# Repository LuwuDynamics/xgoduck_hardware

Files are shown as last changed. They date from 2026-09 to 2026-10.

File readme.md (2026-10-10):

<div align="center">



# XGO-Duck

**English** · [简体中文](README_CN.md)

**Build a robot duck. Explore how it moves. Make it your own.**

A 3D-printable biped robot built around Arduino UNO Q and 15 serial servos.

[Assembly guide](Assembly_Guide.pdf) · [Bill of materials](BOM.md) · [Runtime](https://github.com/LuwuDynamics/xgoduck_runtime_arduino) · [Training](https://github.com/LuwuDynamics/xgoduck_rl)

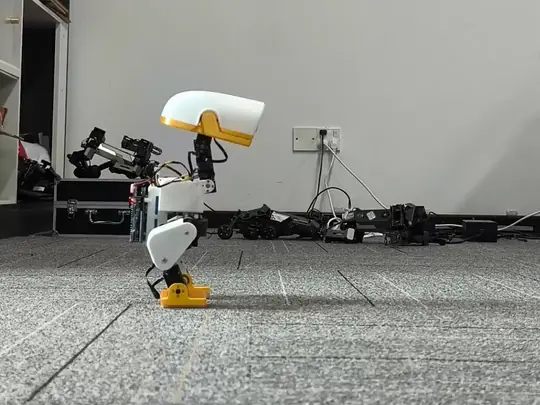
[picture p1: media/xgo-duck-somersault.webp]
A duck-shaped biped robot performing a somersault in a looping animation


*A clean somersault · CyberBionic Maker*

</div>

## Meet XGO-Duck

XGO-Duck is a duck-shaped biped robot adapted by **Luwu Dynamics** from Pollen Robotics' **Microduck**. It combines a printable structure, fifteen Feetech 1910 servos, an Arduino UNO Q, and a custom expansion board with an IMU and servo interfaces.

This repository is the hardware starting point: **print the parts, prepare the electronics, and assemble the robot**. Companion repositories provide the onboard runtime and reinforcement-learning tools, connecting a physical build with motion experiments.

| Build | Run | Experiment |
| --- | --- | --- |
| Print the body, legs, neck, head and soft parts. Assemble with the illustrated guide. | Configure and calibrate the robot through the companion runtime's browser interface. | Study the simulation, train policies and explore your own motions. |
| [Hardware files](#hardware-files) | [Onboard runtime](https://github.com/LuwuDynamics/xgoduck_runtime_arduino) | [RL tools](https://github.com/LuwuDynamics/xgoduck_rl) |

## A closer look

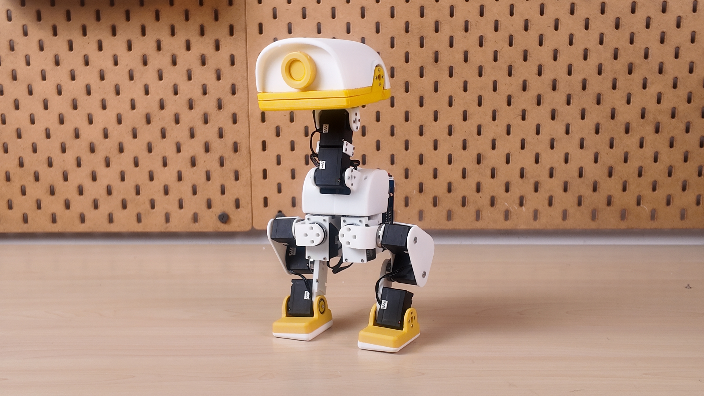
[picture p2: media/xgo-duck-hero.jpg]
XGO-Duck standing on a workbench, with a white printed body, yellow beak and feet, and exposed leg joints


*XGO-Duck prototype — printed parts, articulated legs, and a movable head and beak.*

<table>
  <tr>
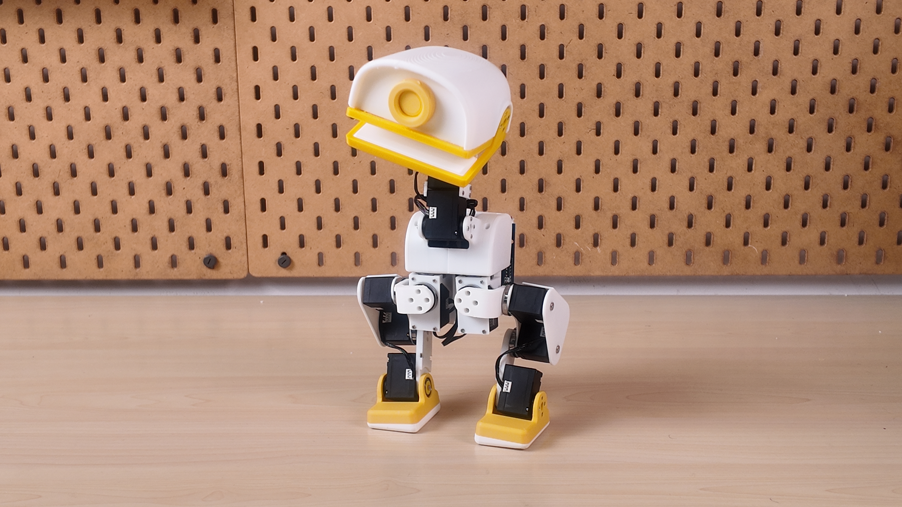
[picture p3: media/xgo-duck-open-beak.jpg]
Front view of XGO-Duck with its beak open
    <td align="center" width="62%"><br><strong>A movable head and beak</strong><br>Four neck/head joints and a separate mouth servo.</td>
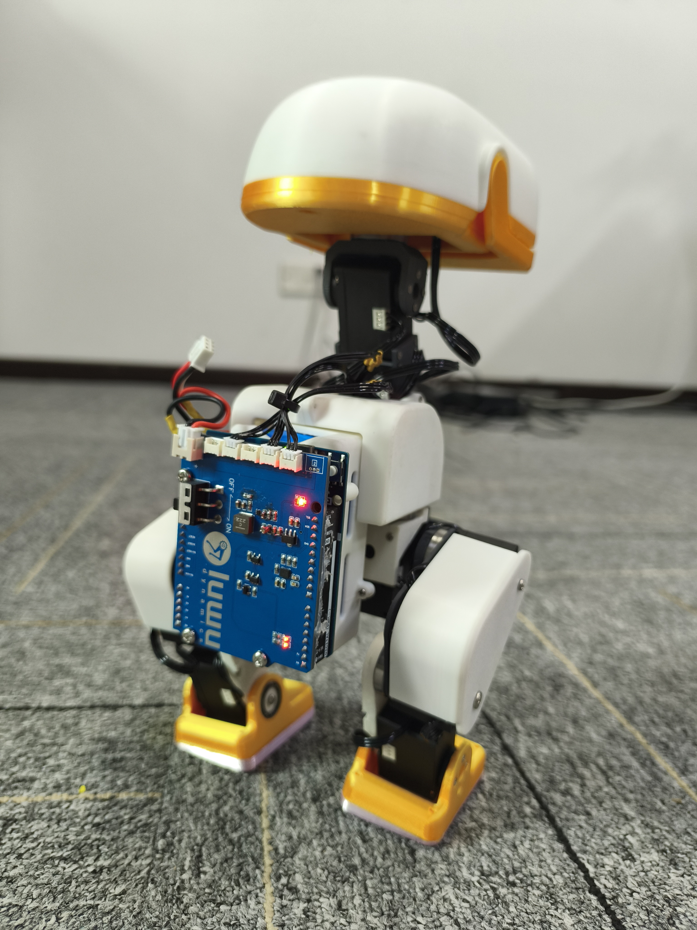
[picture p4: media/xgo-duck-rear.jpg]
Rear prototype view showing the blue expansion board and servo wiring
    <td align="center" width="38%"><br><strong>Electronics you can inspect</strong><br>Rear-mounted controller stack and accessible wiring.</td>
  </tr>
</table>

The photos show project prototypes. Follow the assembly guide and matching board files for your build revision.

## Hardware at a glance

| Subsystem | What it uses | Role |
| --- | --- | --- |
| Controller | Arduino UNO Q | Linux host for policy inference and web UI; STM32 MCU for servo and sensor communication |
| Actuation | 15 Feetech 1910 serial servos | 10 leg joints, 4 neck/head joints, and 1 mouth joint |
| Expansion board | Luwu UNO Q expansion board | Power distribution, servo connections and IMU integration |
| Motion sensing | QMI8658A 6-axis IMU | Acceleration and angular-velocity feedback |
| Structure | STL parts | Body, leg, neck and head components |
| Soft parts | TPU-designated STL files | Foot soles and mouth parts |

The motion policy outputs targets for **14 joints**; the mouth servo is controlled separately. Component details and purchasing checks are collected in the [BOM notes](docs/BOM.md).

### How the system connects

```mermaid
flowchart TD
    UI[Browser: setup, calibration and control] <--> HOST[UNO Q Linux: ONNX policy and web UI]
    RL[Training computer: simulation and RL] -->|Export ONNX policy| HOST
    HOST <-->|Arduino Bridge| MCU[UNO Q STM32: servo and IMU loop]
    MCU <-->|Serial bus| SERVOS[15 Feetech 1910 servos]
    IMU[QMI8658A IMU] -->|Sensor feedback| MCU
    BOARD[Custom expansion board] --- SERVOS
    BOARD --- IMU
```

This is a functional overview; use the board design and assembly documentation for electrical connections.

## Start your build

> **Hardware correction — 2026-10-02:** The old ArduinoUnoQ PCB reverses GND and SIGNAL on **U3, U4 and U5**. Owners of previously manufactured boards should disconnect power and follow the [old-board wiring instructions](PCBA/README.md#english-notice-for-previously-manufactured-boards). Pin 2 power is unchanged. Schematic and PCB sources are updated.

### 1. Prepare parts and electronics

Open the [bill of materials](BOM.md) for the robot purchasing list, supplier links and battery requirements, and [PCBA/](PCBA/) for the expansion-board files. The robot BOM and PCB manufacturing BOM serve different purposes: a finished expansion board already includes its board-level components.

| Part | Quantity |
| --- | ---: |
| Arduino UNO Q (2 GB / 4 GB) | 1 |
| [Robot expansion board — Luwu Dynamics Store](https://shop.xgorobot.com/products/robot-driver-board?variant=67594424713467) | 1 |
| Feetech 1910 servo | 15 |
| AMP 3-pin servo cable | 15 |
| Battery pack, listed as “18650 battery 8.4V” | 1 |
| 8.4 V Li-ion battery charger with 5.5 × 2.1 mm DC barrel plug (DC5521) | 1 |
| M2 × 6 countersunk, flat-end self-tapping screw | 200 |
| M2.3 × 8 flat-top round-head, flat-end self-tapping screw | 6 |
| M3 × 16 round-head machine screw | 4 |
| 10 × 15 × 3 mm bearing | 2 |
| 16 × 22 × 4 mm bearing | 11 |

Quantities reproduce the purchasing list, including screw quantities. Confirm the pack, charger, connector polarity and power requirements using the [component notes](docs/BOM.md) before sourcing or powering the build.

**Identify the three fasteners before ordering.** Items 7 and 8 are self-tapping screws with flat ends. Items 8 and 9 share the same rounded side profile; item 8 has a flat top, while item 9 has the gently domed top shown in the photo below and a machine thread. The following shape guide is illustrative. See the [product photo and size references](BOM.md#fastener-identification) in the BOM.

Shape guide for the M2 by 6 countersunk flat-end self-tapping screw, M2.3 by 8 flat-top round-head flat-end self-tapping screw, and M3 by 16 domed round-head machine screw

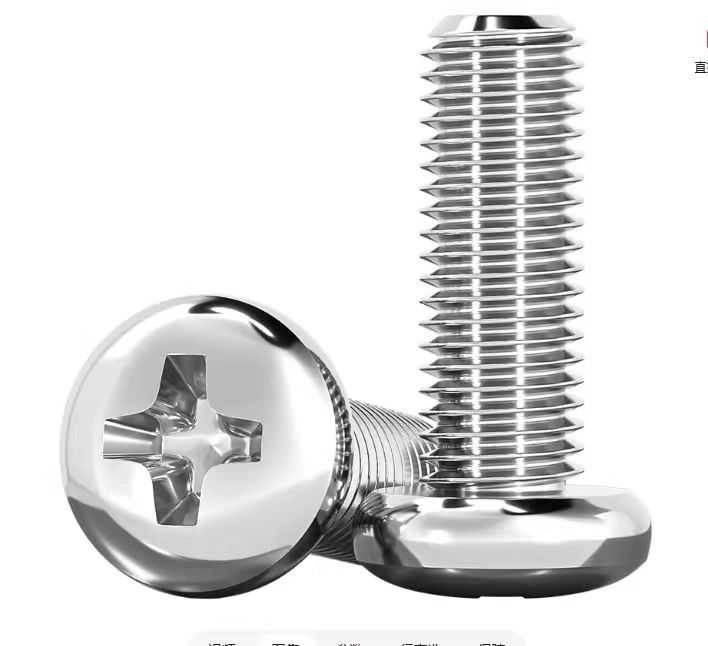
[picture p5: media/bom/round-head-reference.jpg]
Reference photo of the intended shallow, gently domed round screw head for item 9 only


*Item 9 has the domed top shown here. Item 8 has the same rounded sides but a flat top. The photo is a head-style reference, not a size or thread specification.*

### 2. Print the structure

Download the models from [structure/](structure/). The filenames carry useful assembly information:

| Filename pattern | Meaning | Example |
| --- | --- | --- |
| `2x_` | Print two copies | `2x_shank.stl` |
| `left_` / `right_` | Separate left and right parts | `left_foot.stl`, `right_foot.stl` |
| `tpu` | Flexible part | `2x_foot_bottom_tpu.stl`, `mouth_up_tpu.stl` |

Use the [print inventory](docs/PRINTING.md) to track parts. Test a servo mount and bearing fit before printing the full set; a complete validated print profile is still to be documented.

### 3. Configure servos and assemble

Prepare each servo's ID and center position using the [runtime setup instructions](https://github.com/LuwuDynamics/xgoduck_runtime_arduino#first-time-servo-setup), then follow [Assembly_Guide.pdf](Assembly_Guide.pdf).

| Assembly reference | Focus |
| --- | --- |
| Page 1 | Servo ID placement |
| Pages 2–5 | Shaft preparation, initial structure and cable routing |
| Pages 6–15 | Legs, feet and soles |
| Pages 16–23 | Head and neck mechanisms |
| Pages 24–25 | Final assembly |

The [build guide](docs/BUILD_GUIDE.md) adds preparation and inspection checkpoints. Configure one servo at a time, label its ID, and leave cable clearance through each joint's movement.

### 4. Calibrate and bring it to life

Install the [onboard runtime](https://github.com/LuwuDynamics/xgoduck_runtime_arduino), verify servo and IMU feedback, and complete calibration with the robot supported. Start with the default pose before motion trials.

The runtime includes **walk, get-up and pick policies**, plus separate mouth control. Their behavior depends on the assembled hardware, calibration and test conditions. Using the bundled policies does not require training a new model.

## Hardware files

| Path | Contents |
| --- | --- |
| [Assembly_Guide.pdf](Assembly_Guide.pdf) | 25-page illustrated assembly reference |
| [BOM.md](BOM.md) | Whole-robot purchasing list, supplier links and battery reference image |
| [structure/](structure/) | Printable STL models |
| [PCBA/ArduinoUnoQ.SchDoc](PCBA/ArduinoUnoQ.SchDoc) | Altium schematic source |
| [PCBA/ArduinoUnoQ.PcbDoc](PCBA/ArduinoUnoQ.PcbDoc) | Altium PCB source |
| [PCBA/ArduinoUnoQ.pdf](PCBA/ArduinoUnoQ.pdf) | Board layout and dimension drawing |
| [PCBA/ArduinoUnoQ.DWG](PCBA/ArduinoUnoQ.DWG) · [STEP model](PCBA/ArduinoUnoQ.step) | Board outline and mechanical integration model |
| [PCBA/BOM.xlsx](PCBA/BOM.xlsx) · [Pick-and-place data](PCBA/Pick%20Place%20for%20ArduinoUnoQ.csv) | Expansion-board assembly materials and placement coordinates |
| [docs/](docs/) | Build, printing, BOM and troubleshooting notes |

## From hardware to your own behavior

| Repository | Purpose |
| --- | --- |
| **[xgoduck_hardware](https://github.com/LuwuDynamics/xgoduck_hardware)** | Mechanical parts, electronics, BOM and assembly |
| **[xgoduck_runtime_arduino](https://github.com/LuwuDynamics/xgoduck_runtime_arduino)** | UNO Q firmware, policy execution, browser setup and control |
| **[xgoduck_rl](https://github.com/LuwuDynamics/xgoduck_rl)** | Simulation, reinforcement-learning training and policy export |

Keep the hardware, runtime and policy revisions together in your build record. This makes it easier to reproduce a working configuration and diagnose changes.

## Origins and contributions

XGO-Duck builds on [Microduck](https://github.com/pollen-robotics/microduck) and [microduck_rl](https://github.com/pollen-robotics/microduck_rl) by **Pollen Robotics**. The duck form, 15-servo arrangement and policy joint order originate in that work. Luwu Dynamics' adaptation focuses on **Arduino UNO Q, Feetech 1910 servos, the custom expansion board, and the matching software/model integration**. See [origins and adaptations](UPSTREAM.md).

Build reports, tested print settings, clearer assembly photos and reproducible fixes are welcome. Read [CONTRIBUTING.md](CONTRIBUTING.md) or [open an issue](https://github.com/LuwuDynamics/xgoduck_hardware/issues).

For reuse terms, consult [LICENSING.md](LICENSING.md) and the applicable file-level notices. Contact: **hello@xgorobot.com**.

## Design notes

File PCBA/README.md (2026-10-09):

# ArduinoUnoQ PCBA

## 合作 PCB 供应商 / PCB supplier contact

**深圳诚和欣科技有限公司**是陆吾智能的合作 PCB 供应商。开发者如需咨询本项目 PCB 制作相关事宜，可通过以下方式联系。

Developers can contact Luwu Dynamics' partner PCB supplier below about PCB manufacturing for this project.

| 项目 / Item | 信息 / Details |
| --- | --- |
| 公司 / Company | 深圳诚和欣科技有限公司 |
| 联系人 / Contact | 刘晓亚 / Liu Xiaoya |
| 电话 / Phone | +86 13537846596 |
| 邮箱 / Email | [liu@chxpcba.com](mailto:liu@chxpcba.com) |
| 地址 / Address | 深圳市宝安区西乡簕竹角鸿都工业园 3 栋 2 楼 1 区 / Area 1, 2nd Floor, Building 3, Hongdu Industrial Park, Lezhujiao, Xixiang, Bao'an District, Shenzhen, China |

咨询时建议注明 **XGO-Duck / ArduinoUnoQ 扩展板**，并提供所用工程版本、制作数量及需求，便于沟通与报价。

When enquiring, mention **XGO-Duck / ArduinoUnoQ expansion board** and include the design revision, quantity and requirements to help the supplier prepare a quotation.

## 中文：已生产 PCB 的处理说明（2026-10-02）

**U3、U4、U5 舵机接口的 GND 与 SIGNAL 在旧版设计中接反。使用旧文件生产的 PCB，请先断电核对并处理，再连接舵机。U2 是稳压器，不属于此次换线范围。**

本次更新替换 `ArduinoUnoQ.SchDoc` 和 `ArduinoUnoQ.PcbDoc`。下面的旧版映射已在更新前的提交 [`703bfd2`](https://github.com/LuwuDynamics/xgoduck_hardware/tree/703bfd274071cb545b1ed6f512f3c81cf91e447b/PCBA) 中核实；更早批次请按实际网络测量确认，不能仅凭下载日期判断。

| 接口 | 引脚号 | 旧 PCB 网络 | 2026-10-02 修订文件网络 |
| --- | --- | --- | --- |
| U3 / U4 / U5 | 1 | GND | SIGNAL |
| U3 / U4 / U5 | 2 | VCC8.4V | VCC8.4V（不变） |
| U3 / U4 / U5 | 3 | SIGNAL | GND |

以上编号是工程内的焊盘编号，不代表从任意观察方向看到的左、中、右。确认插头朝向和焊盘编号，不要只凭线色或旧图纸判断。

### 已生产旧板：优先使用换线或专用转接线

1. 断开电池、USB 和其他电源，拔下舵机及外接线束。用旧版工程和万用表通断测量，确认实际板卡符合上表“旧 PCB 网络”。
2. 对每一路实际使用的 U3、U4、U5，在**板端插头这一端**交换 GND 与 SIGNAL 两根线的端子（对应 1、3 号位置），2 号电源线保持原位；也可制作专用交叉转接线。舵机端保留其原本正确的接线。不要把插头强行反插，也不要在同一线束两端都交换，否则会抵消修正。
3. 断电状态下逐线确认：板卡 GND 最终到舵机 GND、VCC8.4V 到舵机电源、SIGNAL 到舵机信号；确认电源与地没有短接，端子锁止可靠、没有裸露导体。
4. 确认线路后，在机器人可靠支撑、具有限流保护的条件下先做单个舵机通信测试，再逐路恢复。若不能可靠识别针位或测量结果不符，停止接线并联系 `hello@xgorobot.com`。
5. 给改过的线束标明“仅用于旧版 ArduinoUnoQ 板”。切换到修订 PCB 时，应恢复标准线束，不能继续使用这条交叉线。

该方法补偿旧 PCB 的接口顺序，不改变板上铜箔。若需把旧板改成标准线束可直接使用的版本，应由有经验的人员根据实际铜层连接制定割线、隔离及飞线方案，并验证断开和重连结果；这里未验证具体割线点位，不提供可直接照做的割线图。不要直接短接 GND 和 SIGNAL。

### 尚未生产的用户

使用此次修订的 `.SchDoc` 和 `.PcbDoc`，在 Altium 中检查原理图与 PCB 一致性，重新铺铜并运行 ERC/DRC，再重新生成 Gerber、钻孔及所需生产资料。

## English: notice for previously manufactured boards

**The old design reverses GND and SIGNAL on servo connectors U3, U4 and U5. Disconnect power and check affected boards before connecting servos. U2 is a regulator and is not part of this connector correction.**

The old PCB at commit `703bfd274071cb545b1ed6f512f3c81cf91e447b` has pin 1 = GND, pin 2 = VCC8.4V, pin 3 = SIGNAL. The supplied 2026-10-02 revision changes this to pin 1 = SIGNAL, pin 2 = VCC8.4V, pin 3 = GND. These are CAD pad numbers, not a left-to-right viewing convention. Verify other production batches by their actual connectivity.

For a confirmed old board, swap the GND and SIGNAL terminals **at the board end only** of each affected cable, or use a dedicated crossover adapter. Keep power on pin 2 and retain the correct servo-end wiring. Do not force a keyed plug backwards or swap both ends of the same cable. With all power removed, verify board GND reaches servo GND, power reaches servo power, and signal reaches servo signal; check for a power-to-ground short and secure the terminals. Start with one servo and current-limited power while supporting the robot. Label the modified cable for old-board use only; use normal wiring with the revised board. Contact `hello@xgorobot.com` if pin identification or continuity is uncertain.

This is a cable workaround, not a copper repair. No board cutting/jumper locations have been validated; do not bridge GND and SIGNAL. Board-level rework requires a separately verified isolation and reconnection plan.

For new production, use the revised schematic and PCB, check their consistency, repour copper, run ERC/DRC, and regenerate manufacturing outputs.

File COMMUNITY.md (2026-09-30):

# Build, document and contribute

[Project](readme.md) · [Contributing](CONTRIBUTING.md) · [Roadmap](ROADMAP.md)

A useful contribution helps another person reproduce a result. You do not need a complete robot to start.

## Choose a first contribution

| What you can offer | A useful contribution | Where to send it |
| --- | --- | --- |
| A fresh reader's perspective | Identify the exact step that assumes missing knowledge | [Documentation issue](https://github.com/LuwuDynamics/xgoduck_hardware/issues/new?template=documentation.md) |
| A printer and measuring tools | Record fit, material and orientation for one named part | [Build report](https://github.com/LuwuDynamics/xgoduck_hardware/issues/new?template=build_report.md) |
| An assembled robot | Reproduce setup with revisions, calibration procedure and status capture | [Runtime issue](https://github.com/LuwuDynamics/xgoduck_runtime_arduino/issues) |
| A CUDA workstation | Reproduce one task and record checkpoint/export results | [Training issue](https://github.com/LuwuDynamics/xgoduck_rl/issues) |
| Experience with model transfer | Share an ONNX artifact, model card and bounded evaluation | [Policy report](https://github.com/LuwuDynamics/xgoduck_rl/issues/new?template=policy_report.md) |

Templates in this documentation package become available after the corresponding repository changes are merged. Use a regular issue if a template has not reached the live repository yet.

## Share a build people can repeat

Include one clear photo, the hardware/runtime revisions, servo identity, battery specification, print settings, calibration method and a short account of the first successful test. Include failures and fixes. An edited highlight clip can illustrate the result, but a continuous real-time clip with the test conditions is better evidence.

## Share a policy people can evaluate

Provide a model card, source and artifact hashes, exact task, observation/action semantics and hardware compatibility. Separate simulation-only results from real-robot results. Publish only material you have rights to redistribute. A submission is not an official compatibility endorsement.

## Help maintain useful issues

Search existing reports, keep each report focused and include the smallest reproduction. Redact credentials and personal information. Maintainers can ask for missing evidence, link duplicates and summarize verified fixes back into the documentation.

There is no dedicated XGO-Duck community-server link in this release. GitHub issues are the public entry point; hello@xgorobot.com handles private and commercial enquiries. Do not direct XGO-Duck support requests to upstream maintainers unless the issue has been isolated to their project.

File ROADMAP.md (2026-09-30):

# Roadmap

[Project](readme.md) · [Community](COMMUNITY.md)

This is a proposed sequence of improvements, not a delivery schedule. Each milestone needs evidence before it is marked complete.

| Milestone | Current status | Completion evidence |
| --- | --- | --- |
| Understand the system | English documentation prepared locally | Published working links, lineage and clearly scoped licenses |
| Reproduce one build | Parts and assembly resources available; key details pending | Confirmed power/servo specifications, print profiles, mechanical-zero references and an independent build record |
| Reproduce the first motion | Runtime and three policies supplied; this documentation work did not test hardware | Fresh-board install log, calibration record, timing capture and continuous first-motion video |
| Evaluate custom policies | Training/export path documented | Versioned model card, compatible runtime and reported evaluation trials |
| Share community results | Issue/report templates prepared | Maintainer-reviewed builds and policy reports with permission to feature them |

## Good next experiments

Improved printability, clearer wiring diagrams, repeatable actuator characterization and documented calibration can benefit every builder. Additional motion tasks should be integrated and evaluated individually rather than promoted merely because a simulator task exists.

Potential future work includes a validated XGO-Duck browser demo, a tested build-profile library and a catalog of compatible policies. These are proposals, not currently available services. Upstream feature parity and a specific release date are not promised.

To propose work, describe the user benefit, smallest useful change, compatibility impact and evidence that would establish success.

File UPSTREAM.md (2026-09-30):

# Origins and adaptations

[Project](readme.md) · [Licensing](LICENSING.md)

XGO-Duck is a substantial adaptation of the Microduck ecosystem, not an independently originated robot concept. The maintainer has confirmed extensive reference to Microduck materials. The XGO-Duck repository descriptions also identify that lineage. This page records the architectural relationship; it is not a completed file-by-file copyright audit.

## Credit the foundation

- [Microduck, Pollen Robotics](https://pollen-robotics.com/microduck/): the robot concept and upstream project.
- [Microduck runtime](https://github.com/pollen-robotics/microduck): upstream onboard software and system reference.
- [microduck_rl](https://github.com/pollen-robotics/microduck_rl): upstream learning environments and sim-to-real approach.
- [mjlab](https://github.com/mujocolab/mjlab): training framework.
- [BAM, Rhoban](https://github.com/Rhoban/bam): actuator modelling.

## What follows upstream and what is adapted

| Area | Inherited or referenced foundation | XGO-Duck adaptation documented in its source |
| --- | --- | --- |
| Robot form | Duck-shaped biped with articulated legs, neck, head and mouth | Printable XGO-Duck structure and assembly drawings |
| Joint layout | Fifteen servos and retained policy ordering | Feetech 1910 bus integration and per-robot encoder calibration |
| Learning | Microduck task recipes and PPO/ONNX workflow | XGO-Duck geometry/inertias and HLS1910 BAM parameters |
| Control interface | Shared policy conventions and motion concepts | Linux policy host plus STM32 control on Uno Q |
| Electronics | Reference robot architecture | Luwu expansion board with QMI8658A, power and servo interfaces |

“Adaptation” here describes the engineering work visible in the XGO-Duck source. It does not establish exclusive ownership of every file. The exact upstream base revision, copied paths, original design sources and permissions must still be recorded.

## Compatibility is a separate question

Use the XGO-Duck task IDs, dependencies and deployment instructions in these repositories. Do not substitute an upstream policy solely because its tensors have the same dimensions. Actuator dynamics, geometry, calibration, command meaning and runtime behavior must also agree.

Upstream commands such as `robotctl` belong to a different runtime. They are not XGO-Duck Uno Q installation instructions. Features demonstrated on an upstream robot are not evidence that this hardware variant supports them.

## Model and design rights need their own record

The current [upstream RL README](https://github.com/pollen-robotics/microduck_rl) distinguishes its code license from a noncommercial, share-alike statement for 3D models. Preserve the applicable terms for the actual inherited files and versions; obtain the precise license text and provenance before redistributing derivatives. A code LICENSE alone is insufficient evidence for model rights.

The official [Microduck press kit](https://pollen-robotics.com/microduck/press-kit/) also limits its open-source statement to software. Do not infer design-file permissions from product marketing. These observations were reviewed on 2026-09-26 and are not a finding that any specific XGO-Duck file is unauthorized.

## Attribution for articles and demonstrations

Suggested credit: **“XGO-Duck by Luwu Dynamics, based on Microduck and microduck_rl by Pollen Robotics.”** Add mjlab and Rhoban BAM when discussing training. Preserve file-level copyright and license notices in source distributions. This project does not claim endorsement by Pollen Robotics, Hugging Face, Rhoban or Arduino.

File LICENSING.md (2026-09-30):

# Licensing status

No top-level license file was found in the repository snapshot used for this documentation update. Publication of files by itself does not establish a complete reuse grant. Upstream and third-party components retain their applicable terms.

## Maintainer intent for eligible original material

The maintainer intends to allow personal and educational replication and require separate authorization for commercial use of material they have the right to license. This statement records intent; it is not a finalized replacement license and does not override any existing grants or third-party rights. File-level scope and final terms are pending.

A project-wide “noncommercial only” label would be inaccurate where Apache-2.0 or another license already permits commercial use. Noncommercial restrictions also do not meet the OSI definition of open-source software. Describe the actual license of each component rather than claiming the whole project is under one permissive license.

For a commercial enquiry, email **hello@xgorobot.com** with the files/revisions involved, intended product or service, expected quantity and distribution plans. For personal/educational replication of material without final terms, use the same address to confirm applicable permissions.

## Design and model provenance

Code licensing does not establish rights to every model or design asset. Review the upstream findings and file-level scope in the hardware repository's [origins documentation](https://github.com/LuwuDynamics/xgoduck_hardware) before distributing inherited designs. Exact source revisions and applicable notices remain to be recorded.

## Credits

The project builds on [Microduck](https://github.com/pollen-robotics/microduck) and [microduck_rl](https://github.com/pollen-robotics/microduck_rl) by Pollen Robotics. Training uses [mjlab](https://github.com/mujocolab/mjlab) and [BAM](https://github.com/Rhoban/bam). Hardware and software adaptations should be credited without implying endorsement by those projects or Arduino.

References: [OSI Open Source Definition](https://opensource.org/osd), [Apache-2.0 text](https://www.apache.org/licenses/LICENSE-2.0).

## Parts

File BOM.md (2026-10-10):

# XGO-Duck Bill of Materials

[Project overview](readme.md) · [Assembly guide](Assembly_Guide.pdf) · [Component specifications](docs/BOM.md)

Parts and purchasing quantities for one XGO-Duck build, initially transcribed from the robot BOM in Git commit `80be3e2`. The maintainer corrected the fastener descriptions for items 7–9 on 2026-10-10; their quantities are unchanged. Other purchase links and battery requirements are preserved from the original workbook. A dash means no purchase link was supplied.

## Parts list

| No. | Part | Quantity | Purchase link | Specification / notes |
| ---: | --- | ---: | --- | --- |
| 1 | Arduino UNO Q (2 GB / 4 GB) | 1 | [Arduino Store](https://store.arduino.cc/) | — |
| 2 | Robot expansion board | 1 | [Luwu Dynamics Store](https://shop.xgorobot.com/products/robot-driver-board?variant=67594424713467) | See [PCBA design files](PCBA/). |
| 3 | AMP 3-pin cable | 15 | [Feetech servo kit](https://www.alibaba.com/product-detail/Microduck-Servo-Kit-Feetech-Low-Cost_1601942207064.html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) | Shared purchase link with item 4 in the original workbook. |
| 4 | Feetech 1910 servo | 15 | [Feetech servo kit](https://www.alibaba.com/product-detail/Microduck-Servo-Kit-Feetech-Low-Cost_1601942207064.html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) | Shared purchase link with item 3 in the original workbook. |
| 5 | 18650 battery pack, 8.4 V | 1 | — | XH2.54 connector; capacity **> 2,500 mAh**; discharge rating **> 3C**. |
| 6 | 8.4 V Li-ion battery charger | 1 | — | 5.5 × 2.1 mm DC barrel plug (DC5521). |
| 7 | M2 × 6 countersunk, flat-end self-tapping screw | 200 | — | [Shape and photo reference](#fastener-identification) |
| 8 | M2.3 × 8 flat-top round-head, flat-end self-tapping screw | 6 | — | [Shape and photo reference](#fastener-identification) |
| 9 | M3 × 16 round-head machine screw | 4 | — | [Shape and photo reference](#fastener-identification) |
| 10 | Bearing, 10 × 15 × 3 mm | 2 | [Tmall](https://detail.tmall.com/item.htm?id=721793990910&skuId=6237461598360) | — |
| 11 | Bearing, 16 × 22 × 4 mm | 11 | [Tmall](https://detail.tmall.com/item.htm?id=721793990910&skuId=6237461598469) | — |

## Fastener identification

Side-view shape guide for BOM item 7 M2 by 6 countersunk flat-end self-tapping screw, item 8 M2.3 by 8 flat-top round-head flat-end self-tapping screw, and item 9 M3 by 16 domed round-head machine screw

The illustrations distinguish the three head and thread types; they are **not dimensioned drawings or product photos**. Seller pages below show actual fasteners with the matching size option. Select that option and check head, flat end where specified, thread type, drive, material and finish against your build before ordering. These links are photo references, not validated suppliers for this project.

User-supplied reference photo showing the intended low, gently domed round screw head

**Round-head style reference for item 9 only.** This supplied photo clarifies its shallow, domed head profile. Item 8 keeps the **same rounded side profile**, but its **top surface is flat**. The photo does not establish item 9's diameter, length or thread type; use the specifications in the parts list for those details.

| Item | Product photo / size reference |
| ---: | --- |
| 7 | [M2 × 6 countersunk flat-end self-tapping screw](https://www.rakuten.com.tw/shop/longteng010/product/zzc0d6xyk/) — select **M2*6**. |
| 8 | [M2.3 × 8 flat-end self-tapping listing](https://i-item.jd.com/10131153225220.html) — select **M2.3*8**. This is a size/thread reference; its head profile has not been confirmed against the shape guide. |
| 9 | [M3 × 16 round-head machine screw](https://www.partco.fi/en/mechanics/screwsnutswashers/metal-screwsnutwashers/9369-m-ru-m3x16.html). |

## Battery connector reference

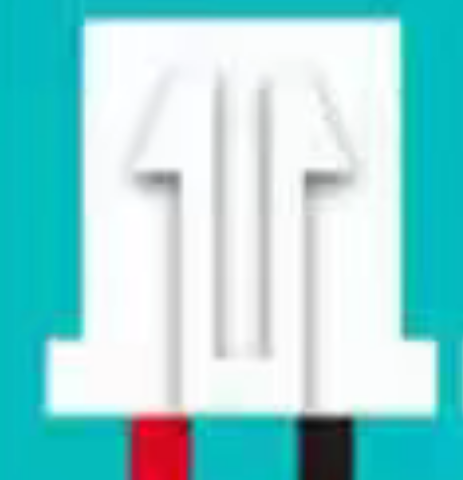
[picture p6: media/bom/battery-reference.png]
Battery connector reference extracted from the original BOM, showing a white connector with red and black wires


Original workbook image accompanying the battery entry. Confirm the mating connector and polarity against the actual board before connection. The image alone does not define a pinout.

## Build notes

- Quantities are the original purchasing quantities, including fasteners. The item 7–9 descriptions reflect the maintainer's 2026-10-10 correction. Follow the [assembly guide](Assembly_Guide.pdf) for installation.
- The battery label and requirements above reproduce the source. Exact pack configuration, compatible charger and polarity require confirmation; see the [battery specification notes](docs/BOM.md#battery-and-charger-specification-still-to-be-finalized).
- Printed parts are available in [structure/](structure/), with a separate [printing inventory](docs/PRINTING.md).
- The [PCB manufacturing BOM](PCBA/BOM.xlsx) lists components for making the expansion board. Those components are already included when using a finished board.

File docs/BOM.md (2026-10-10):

# Bill of materials and component specifications

[Project](../readme.md) · [Purchasing list](../BOM.md) · [Build guide](BUILD_GUIDE.md) · [Print inventory](PRINTING.md)

Quantities come from [the robot purchasing list](../BOM.md), items 1–11. They are purchasing quantities, not a verified installed-fastener count. The maintainer corrected the descriptions for fasteners 7–9 on 2026-10-10 without changing their quantities. Other component specifications below are source-backed; unresolved purchasing details are identified rather than replaced with generic substitutes.

## Robot purchasing list

| Item | Quantity | Specification supported by available sources | Purchasing check |
| --- | ---: | --- | --- |
| Arduino Uno Q (2 GB / 4 GB) | 1 | Qualcomm QRB2210 Linux host + STM32U585 MCU; Arduino App environment | 2 GB and 4 GB variants both confirmed by the maintainer; record which variant your build uses |
| XGO-Duck expansion board | 1 | Drawing envelope 68.55 × 53.38 mm; QMI8658A IMU; servo/power interfaces | Use the matching Luwu board revision; thickness and fabrication stackup are not specified |
| Feetech 1910 serial servo | 15 | Confirmed model: HD-1910-C001 / HD1910M; 34 × 20 × 23 mm; 21 ± 2 g; 4–8.4 V | Maintainer confirms this supplier model; preserve matching firmware/protocol when purchasing replacements |
| Servo cable | 15 | Supplier reference: AMP2.0-3P, 3 positions, 2.0 mm pitch; PVC; 150 ± 5 mm | Verify mating housing, pin orientation and wiring; wire gauge is not supplied |
| Battery pack | 1 | Original BOM: “18650 battery 8.4V”; capacity >2,500 mAh; discharge rating >3C; XH2.54 connector | Pack model, chemistry, nominal voltage, cell arrangement, polarity and charger still need confirmation |
| 8.4 V Li-ion battery charger | 1 | 5.5 × 2.1 mm DC barrel plug (DC5521), as listed in the robot BOM | Confirm charger model, charge current, plug polarity and compatibility with the actual battery pack |
| M2 × 6 countersunk, flat-end self-tapping screws | 200 | 2 mm nominal diameter × 6 mm length; countersunk head; flat end; self-tapping thread | Maintainer correction; drive, material and finish remain unspecified. See [shape and photo references](../BOM.md#fastener-identification). |
| M2.3 × 8 flat-top round-head, flat-end self-tapping screws | 6 | 2.3 mm nominal diameter × 8 mm length; circular head with a flat top; flat end; self-tapping thread | Maintainer correction; do not substitute the servo sheet's M2.5 × 6 output-shaft screw. See [shape and photo references](../BOM.md#fastener-identification). |
| M3 × 16 round-head machine screws | 4 | 3 mm nominal thread diameter × 16 mm length; round head; machine thread | Maintainer correction; drive, pitch, material and finish remain unspecified. See [shape and photo references](../BOM.md#fastener-identification). |
| Bearing, 10 × 15 × 3 mm | 2 | 10 mm bore × 15 mm outside diameter × 3 mm width | Confirm shield/seal, flange, clearance and supplier part number |
| Bearing, 16 × 22 × 4 mm | 11 | 16 mm bore × 22 mm outside diameter × 4 mm width | Confirm shield/seal, flange, clearance and supplier part number |

The [PCBA BOM](../PCBA/BOM.xlsx) is for manufacturing the expansion board. Do not count its components again when buying a finished board. USB data cable, assembly tools, filament and adhesive are not separate entries in the robot purchasing list; account for them when planning the build.

## Controller

The [official Arduino Uno Q documentation](https://docs.arduino.cc/hardware/uno-q/) identifies a Qualcomm QRB2210 MPU with four Cortex-A53 cores at 2.0 GHz, plus an STM32U585 Cortex-M33 MCU up to 160 MHz. The board runs Debian Linux and Arduino sketches over Zephyr. The maintainer confirms that the project uses both 2 GB and 4 GB variants. Record the RAM variant and board SKU in your build report; no comparative performance result is claimed.

Use an Uno Q rather than treating another UNO-family board as interchangeable. Board power-input specifications and the expansion-board battery path are separate interfaces; the servo's 8.4 V maximum is not a voltage recommendation for a logic or USB power pin.

## Servo: supplier specification and runtime configuration

Source: supplied Feetech **HD-1910-C001**, edition **A/0**, dated **2026-09-07**. The cover identifies **HD1910M**. Values below describe that supplier variant. The maintainer confirms that the abbreviated “Feetech 1910” BOM entry refers to this supplied HD-1910-C001 / HD1910M variant. The simulation retains an HLS1910-labelled actuator model; that internal name is not an alternate purchasing SKU.

### Mechanical and interface data

| Parameter | Supplier specification |
| --- | --- |
| Body dimensions | 34 × 20 × 23 mm; use the supplier drawing for shaft and mounting details |
| Mass | 21 ± 2 g per servo |
| Motor / gears | Coreless motor / metal gears |
| Case | PA66 + GF43% |
| Position sensor | 12-bit magnetic encoder |
| Output spline | 25 teeth; 4.95 mm outside diameter |
| Gear ratio | 1:320 |
| Backlash | ≤0.5° |
| Output-shaft screw | M2.5 × 6 |
| Connector / cable | AMP2.0-3P; PVC; 150 ± 5 mm |
| Communication | TTL half-duplex asynchronous serial, 8 data bits, 1 stop bit, no parity |
| Baud range | 38,400 bit/s to 1 Mbit/s; supplier default 1 Mbit/s |
| ID range | 0–253; supplier default ID 1 |
| Encoder range / resolution | 0–4095 over 360°; approximately 0.088° per step |
| Operating temperature | −20 to +60 °C, supplier component rating |

### Electrical data by supply voltage

The working-voltage range is **4–8.4 V**. Typical-voltage columns in the supplier specification are shown separately so torque/current values are not mixed across voltages.

| Parameter | 4.8 V | 6.0 V | 7.4 V |
| --- | ---: | ---: | ---: |
| No-load speed, seconds per 60° | 0.137 | 0.109 | 0.088 |
| No-load current | ≤160 mA | ≤180 mA | ≤210 mA |
| Stall torque | 9 kgf·cm | 12 kgf·cm | 15 kgf·cm |
| Stall current | 1.2 A | 1.6 A | 2.0 A |
| Idle current | 20 mA | 20 mA | 20 mA |
| Rated torque | 2.2 kgf·cm | 3.0 kgf·cm | 3.7 kgf·cm |
| Rated current | 500 mA | 690 mA | 900 mA |

The sheet specifies ±10% for no-load speed, stall torque and stall current. Stall torque is not continuous usable torque or robot lifting capacity. Do not size the full robot supply from one servo's no-load current. No whole-robot current measurement is available here.

### Cable pin definition

| Pin number in supplier connector drawing | Function |
| --- | --- |
| 1 | TTL signal |
| 2 | VCC |
| 3 | GND |

All three conductors are described as black. Identify pin numbers using the supplier's connector view; do not infer left/right orientation from this table or identify polarity by wire color. The mating harness part number, wire gauge and allowable harness current remain unconfirmed.

### Values used by XGO-Duck

| Setting | Current runtime |
| --- | --- |
| Servo bus | 1 Mbit/s, Serial1 |
| IDs | 10–14, 20–24, 30–34 |
| Setup centering position | Raw 2047; supplier neutral is stated as 2048 |
| Run temporary gains | KP 6 / KD 20; mouth KP 10 |
| Setup stored-gain defaults | KP 5 / KD 20 |
| Calibration temporary gains | KP 3 / KD 0 |

These are software settings, not additional purchase specifications. Use the [runtime setup instructions](https://github.com/LuwuDynamics/xgoduck_runtime_arduino); do not change calibration based on a one-count difference in the supplier's neutral label.

## Expansion board

The dimensioned [PCB drawing](../PCBA/ArduinoUnoQ.pdf) gives a **68.55 × 53.38 mm** envelope. It is a board layout/outline drawing, not a rendered circuit schematic. Electrical design source is [ArduinoUnoQ.SchDoc](../PCBA/ArduinoUnoQ.SchDoc); PCB source is [ArduinoUnoQ.PcbDoc](../PCBA/ArduinoUnoQ.PcbDoc).

| Component / interface | Board quantity | Identifier and known parameter |
| --- | ---: | --- |
| IMU | 1 | U1: QMI8658A, 6-axis; runtime I²C at 400 kHz, probes 0x6A then 0x6B |
| 5 V regulator | 1 | U2: h7651-50pr, as listed in PCBA BOM |
| 3.3 V regulator | 1 | Q2: AMS1117-3.3V, as listed; verify exact orderable part/package against footprint |
| Serial buffers | 2 | SN1: SN74LVC1G126; SN2: SN74LVC1G125 |
| 2.0 mm 3-position headers | 3 | U3–U5: TE 292253-3, right-angle through-hole AMP CT |
| 1.25 mm 3-position headers | 3 | P1–P3: MX 1.25-WI-3P footprint; full manufacturer SKU absent |
| Battery connector | 1 | CN1: ZX-XH2.54-2PWZ; verify actual mating connector and polarity |
| DC socket | 1 | DC1: kh-dc-007b-2.1g; plug drawing and polarity require confirmation |
| Power switch | 1 | SW1: SS-12D06L5 |

The [TE manufacturer listing](https://www.te.com/en/product-292253-3.html) confirms the header's part number, three positions, 2 mm pitch and right-angle mounting. It does not establish that every generic “AMP 3-pin” cable mates correctly.

The original PCBA workbook retains garbled description fields and incomplete sourcing data. Regulator names and connector labels are not a validated continuous-current specification for the assembled board. Fabrication layer stack, thickness, trace/load limits, battery polarity and a board bring-up record still need release documentation.

## Fasteners and bearings

Use the dimensions in the purchasing table; no bearing series code is assigned from dimensions alone. Shields, seals and flanges affect fit and friction. The [fastener shape guide, supplied item-9 head photo and product references](../BOM.md#fastener-identification) help distinguish the three screw entries. Items 8 and 9 have the same rounded side profile; item 8 has a flat top, while the supplied photo establishes the gently domed top of item 9 only. The photo does not establish size or thread. Screw thread type, head profile and drive must match the actual part; do not replace a self-tapping fastener with a machine screw or vice versa.

The servo supplier sheet specifies an **M2.5 × 6 output-shaft screw**. That specification is separate from whole-robot BOM item 8, which the maintainer has corrected to **M2.3 × 8 flat-top round-head, flat-end self-tapping**, quantity six. The available documents do not establish whether the output-shaft screws are included with the servos or how many are installed. Check the actual servo kit and assembly before buying separate output-shaft screws.

## Battery and charger: specification still to be finalized

Confirmed from the original BOM: one pack described as **18650 / 8.4 V**, **capacity >2,500 mAh**, **discharge rating >3C**, with an **XH2.54** connector reference.

The entry does not establish chemistry, nominal versus charge-limit voltage, series/parallel configuration, BMS/protection, dimensions, wire size or connector polarity. A 2-series lithium-ion pack is a possible interpretation, not a verified specification. The BOM specifies one **8.4 V Li-ion battery charger with a 5.5 × 2.1 mm DC barrel plug (DC5521)**. The exact charger model, charge current and plug polarity are not supplied. Confirm compatibility with the actual pack before selecting a charger.

The maintainer must identify the actual pack and compatible charger, then verify mechanical fit and the complete power path under load. The approximately one-hour battery-life target remains an estimate.

## Printed materials and workshop items

The local beta 3MF saves PLA presets for rigid parts on an A1 with a 0.4 mm nozzle and 0.2 mm layer height. That is a saved configuration, not a completed print-validation result. Explicit `_tpu` parts require a separately matched TPU setup; grade/hardness and material quantities are not yet provided. See [PRINTING.md](PRINTING.md).

For assembly, prepare screwdrivers matching the confirmed drives, a multimeter, a stable robot support and a USB data cable suitable for your Uno Q setup. The assembly guide includes an adhesive step; adhesive type and quantity must be selected for the actual printed materials and validated joint. These are preparation requirements, not additions with invented quantities to the source BOM.

## Budget and source record

The maintainer estimates **approximately US$400** per build. No itemized quote is validated. Record supplier, exact SKU, quantity, unit price, currency/date, shipping, taxes, filament, tools and spares for a reproducible budget.

- Robot purchasing list: `BOM.md`, items 1–11; initially transcribed from the robot BOM in Git commit `80be3e2`. The maintainer corrected fastener descriptions 7–9 on 2026-10-10; quantities are unchanged.
- Fastener photo references: linked from `BOM.md`; seller images illustrate matching-size product options but do not establish the project supplier, drive, material or finish.
- Maintainer confirmation in this documentation session: both Uno Q 2 GB and 4 GB variants are used; the supplied HD-1910-C001 / HD1910M specification identifies the project servo.
- Supplier servo document: HD-1910-C001 A/0, 2026-09-07; printed pages 2/7 and 3/7 (PDF pages 3 and 4) for the ratings above. Local original SHA-256: `aafd3b6a03f4902f74164bf49091d88c01418b12ddf7d5f8118cbc763f03f9a9`.
- Expansion-board components: `PCBA/BOM.xlsx`, ArduinoUnoQ sheet; dimensions visually checked in `PCBA/ArduinoUnoQ.pdf`.
- Software settings: runtime `sketch/duck_config.h` and documented setup procedure.
- Controller and connector manufacturer references linked above, checked on 2026-09-26.

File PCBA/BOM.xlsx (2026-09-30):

Comment | Description | Designator | Footprint | Quantity
10uF/25V | 0603贴片电容，±10%，50V | C1, C3, C8, C10 | C0603 | 4
100nF/25V | 0603贴片电容，±10%，50V, 贴片电容 | C2, C4, C5, C9, C11 | C0603 | 5
6.8uF/25V | 0603贴片电容，±10%，50V | C6 | C0603 | 1
1uF/25V | 0603贴片电容，±10%，50V | C7 | C0603 | 1
ZX-XH2.54-2PWZ | 插针结构:1x2P;间距:2.5mm;安装方式:弯插;参考系列:XH;总PIN数:2P;排数:1;每排PIN数:2;行距:-;额定电流:2A;触头材质:黄铜;触头镀层:锡;工作温度:-25℃~+85℃; | CN1 | CONN-TH_2P-P2.50_ZX-XH2.54-2PWZ | 1
LED/R | Typical INFRARED GaAs LED | D3, D4 | D_SOD_523 | 2
kh-dc-007b-2.1g | 连接器类型:DC电源插座;安装方式:弯插;触点内径:-;触点外径:-;额定电流:3A;额定电压:50V;工作温度:-30℃~+70℃; | DC1 | DC-IN-TH_KH-DC-007B-2.1G | 1
pz254v-11-06p | 插针结构:1x6P;间距:2.54mm;行距:-;圆针/方针:方针;安装方式:直插;排数:单排;总PIN位数:6P;额定电流:3A;额定电压:-;配合针长度:6mm;塑高:2.5mm;端接针长度:3mm;触头材质:黄铜;触头镀层:金;工作温度:-40℃~+105℃;颜色:黑色; | H1 | HDR-TH_6P-P2.54-V-M-1 | 1
pz254v-11-10p | 插针结构:1x10P;间距:2.54mm;行距:-;圆针/方针:方针;安装方式:直插;排数:单排;总PIN位数:10P;额定电流:3A;额定电压:250V;配合针长度:6mm;塑高:2.5mm;端接针长度:3mm;触头材质:黄铜;触头镀层:-;工作温度:-40℃~+105℃;颜色:黑色; | H2 | HDR-TH_10P-P2.54-V-M | 1
pz254v-11-08p | 插针结构:1x8P;间距:2.54mm;行距:-;圆针/方针:方针;安装方式:直插;排数:单排;总PIN位数:8P;额定电流:3A;额定电压:250V;配合针长度:6mm;塑高:2.5mm;端接针长度:3mm;触头材质:黄铜;触头镀层:-;工作温度:-40℃~+105℃;颜色:黑色; | H3, H4 | HDR-TH_8P-P2.54-V-M | 2
Header 3 | Header, 3-Pin | P1, P2, P3 | MX 1.25-WI-3P | 3
BC807 | 三极管BJT | Q1 | SOT-23-3 | 1
AMS1117-3.3V | 输入18V 输出3.3V 1A，SOT-89封装 | Q2 | SOT-89-3_L4.5-W2.5-P1.50-LS4.2-BR | 1
10K/±1% | Resistor | R1, R5, R8 | R0603 | 3
4.7K/±1% | Resistor | R2, R3, R4 | R0603 | 3
1k/±1% | Resistor | R9 | R0603 | 3
3.3K/±1% | Resistor | R10 | R0603 | 1
20K/±1% | Resistor | R11 | R0603 | 1
SN74LVC1G126 | 输出缓冲器 | SN1 | SOT_23_5 | 1
SN74LVC1G125 | 输出缓冲器 | SN2 | SOT_23_5 | 1
SS-12D06L5 | 电路结构:单刀双掷;安装方式:-;开关颜色:黑色;额定电流:3A;额定电压:125V;工作寿命:1万次; | SW1 | SW-TH_3P-P4.70_L11.1-W12.7 | 1
QMI8658A | 六轴陀螺仪 陀螺仪量程(MAX) ±2048dps 加速度计量程(MAX) ±16g | U1 | LGA-14_L3.0-W2.5-P0.50-TL | 1
h7651-50pr | 输出极性:正极;工作电压:8.5V;输出电压:5V;输出电流:1A;电源纹波抑制比(PSRR):-;输出类型:固定; | U2 | SOT-89-3_L4.5-W2.5-P1.50-LS4.2-BR | 1
292253-3 | 插针结构:1x3P;间距:2mm;安装方式:弯插;总PIN数:3P;排数:1;每排PIN数:3;额定电流:4A;触头材质:黄铜;触头镀层:锡;工作温度:-40℃~+105℃; | U3, U4, U5 | CONN-TH_3P-P2.00_TE_292253-3 | 3

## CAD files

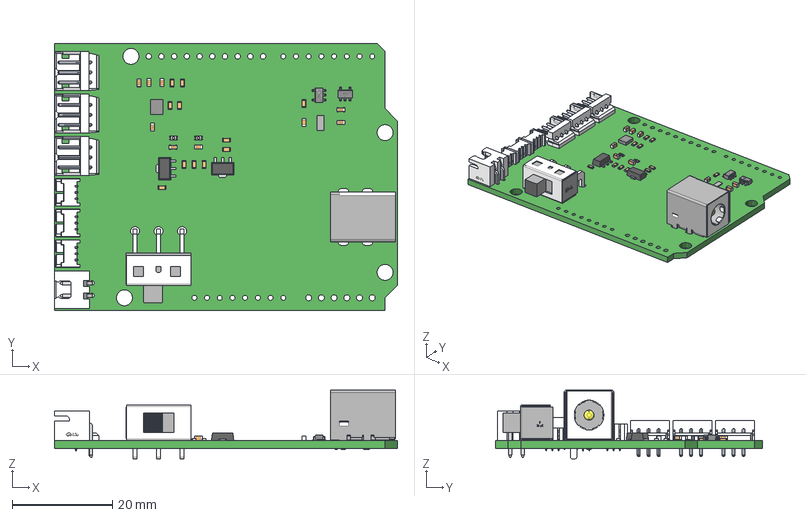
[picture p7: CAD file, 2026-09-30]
PCBA/ArduinoUnoQ.step
68.6 x 53.4 x 13.8 mm
CONN-TH_3P-P2.00_TE_292253-3~CONN-TH_3P-P2.00_TE_292253-3~qq6q x 3
CONN-TH_3P-P2.00_TE_292253-3~CONN-TH_3P-P2.00_TE_292253-3~qq6q001 x 3
CONN-TH_3P-P2.00_TE_292253-3~CONN-TH_3P-P2.00_TE_292253-3~qq6q002 x 3
CONN-TH_3P-P2.00_TE_292253-3~CONN-TH_3P-P2.00_TE_292253-3~qq6q003 x 3
CONN-TH_3P-P2.00_TE_292253-3~CONN-TH_3P-P2.00_TE_292253-3~qq6q004 x 3
CONN-TH_3P-P2.00_TE_292253-3~CONN-TH_3P-P2.00_TE_292253-3~qq6q005 x 3
CONN-TH_3P-P2.00_TE_292253-3~CONN-TH_3P-P2.00_TE_292253-3~qq6q006 x 3
CONN-TH_3P-P2.00_TE_292253-3~CONN-TH_3P-P2.00_TE_292253-3~qq6q007 x 3
CONN-TH_3P-P2.00_TE_292253-3~CONN-TH_3P-P2.00_TE_292253-3~qq6q008 x 3
CONN-TH_3P-P2.00_TE_292253-3~CONN-TH_3P-P2.00_TE_292253-3~qq6q009 x 3
CONN-TH_3P-P2.00_TE_292253-3~CONN-TH_3P-P2.00_TE_292253-3~qq6q010 x 3
CONN-TH_3P-P2.00_TE_292253-3~CONN-TH_3P-P2.00_TE_292253-3~qq6q011 x 3
CONN-TH_3P-P2.00_TE_292253-3~CONN-TH_3P-P2.00_TE_292253-3~qq6q012 x 3
CONN-TH_3P-P2.00_TE_292253-3~CONN-TH_3P-P2.00_TE_292253-3~qq6q013 x 3
CircuitWorks-SOT-89 x 2
0603_C x 9
DC-IN-TH_KH-DC-007B-2.1G~DC-IN-TH_KH-DC-007B-2.1G~BMZG
DC-IN-TH_KH-DC-007B-2.1G~DC-IN-TH_KH-DC-007B-2.1G~BMZG001
LOGOԲ x 2
LED 0603-W x 2
C0603_040 x 33
User Library-LGA-14L
SW-TH_3P-P4.70_L11.1-W12.7~SW-TH_3P-P4.70_L11.1-W12.7~vEMC
SW-TH_3P-P4.70_L11.1-W12.7~SW-TH_3P-P4.70_L11.1-W12.7~vEMC001
SW-TH_3P-P4.70_L11.1-W12.7~SW-TH_3P-P4.70_L11.1-W12.7~vEMC002
SW-TH_3P-P4.70_L11.1-W12.7~SW-TH_3P-P4.70_L11.1-W12.7~vEMC003
SW-TH_3P-P4.70_L11.1-W12.7~SW-TH_3P-P4.70_L11.1-W12.7~vEMC004
SW-TH_3P-P4.70_L11.1-W12.7~SW-TH_3P-P4.70_L11.1-W12.7~vEMC005
SW-TH_3P-P4.70_L11.1-W12.7~SW-TH_3P-P4.70_L11.1-W12.7~vEMC006
SW-TH_3P-P4.70_L11.1-W12.7~SW-TH_3P-P4.70_L11.1-W12.7~vEMC007
SW-TH_3P-P4.70_L11.1-W12.7~SW-TH_3P-P4.70_L11.1-W12.7~vEMC008
SW-TH_3P-P4.70_L11.1-W12.7~SW-TH_3P-P4.70_L11.1-W12.7~vEMC009
SW-TH_3P-P4.70_L11.1-W12.7~SW-TH_3P-P4.70_L11.1-W12.7~vEMC010
SW-TH_3P-P4.70_L11.1-W12.7~SW-TH_3P-P4.70_L11.1-W12.7~vEMC011
SW-TH_3P-P4.70_L11.1-W12.7~SW-TH_3P-P4.70_L11.1-W12.7~vEMC012
SW-TH_3P-P4.70_L11.1-W12.7~SW-TH_3P-P4.70_L11.1-W12.7~vEMC013
CONN-TH_2P-P2.50_ZX-XH2.54-2PWZ~CONN-TH_2P-P2.50_ZX-XH2.54-2PWZ~FRk7
User Library-SOT23-5_SOT23-5 Connector_Default x 10
User Library-SOT23-5_SOT23-5 Body_Default x 2
Extruded
MOLEX1.25-WI-ӽ½À x 9
LOGOԲ0.25 x 3
MOLEX1.25-WI-3P x 3

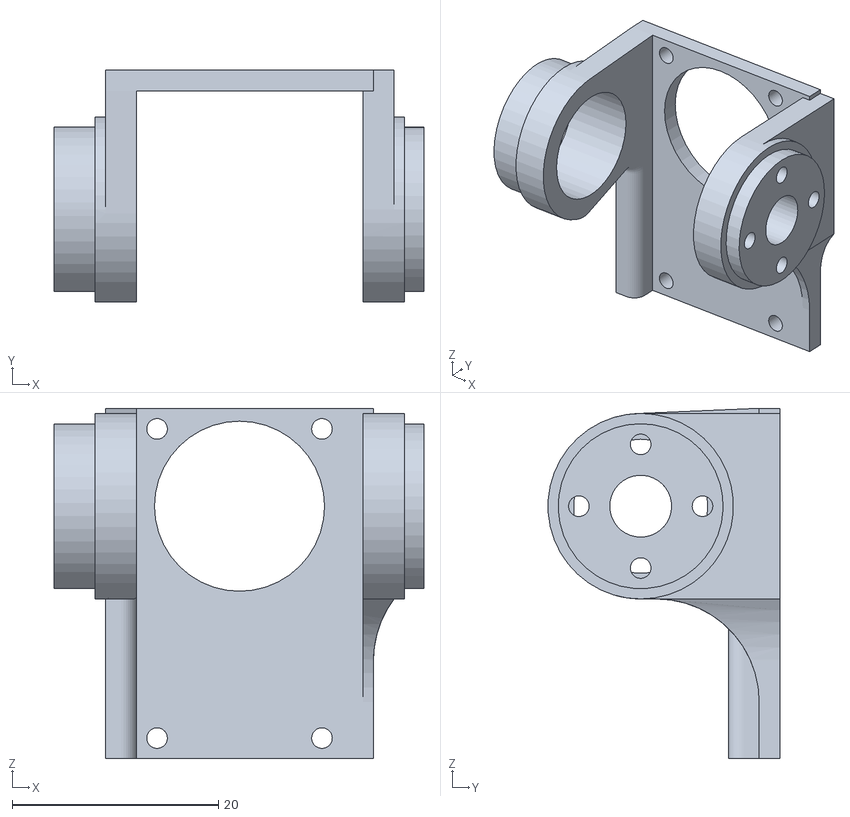
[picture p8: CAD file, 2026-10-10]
structure/head_yaw.STL
35.9 x 22.5 x 34.0

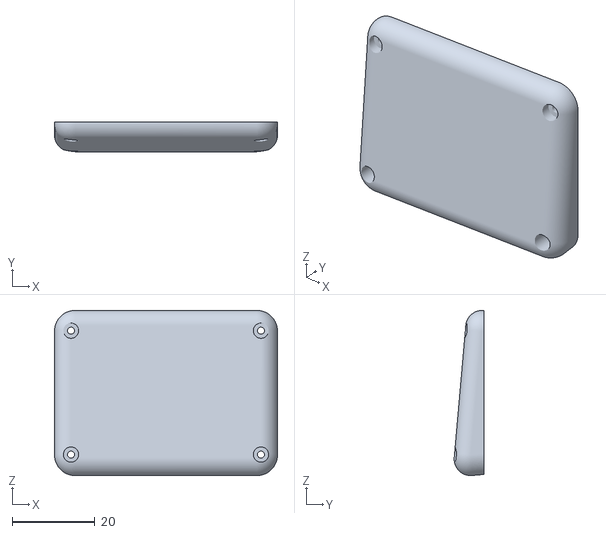
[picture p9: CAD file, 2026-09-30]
structure/2x_foot_bottom_tpu.stl
54.0 x 7.20 x 40.0

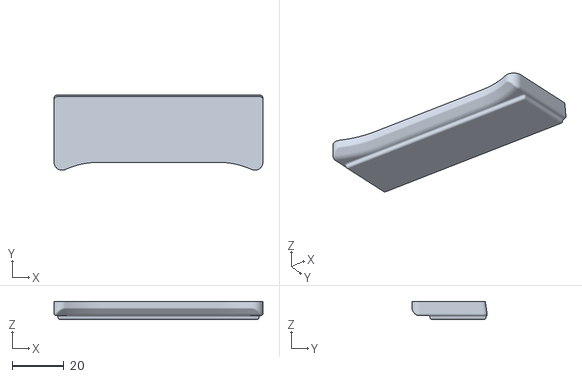
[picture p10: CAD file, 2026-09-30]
structure/mouth_buttom_tpu.stl
80.6 x 29.1 x 7.00

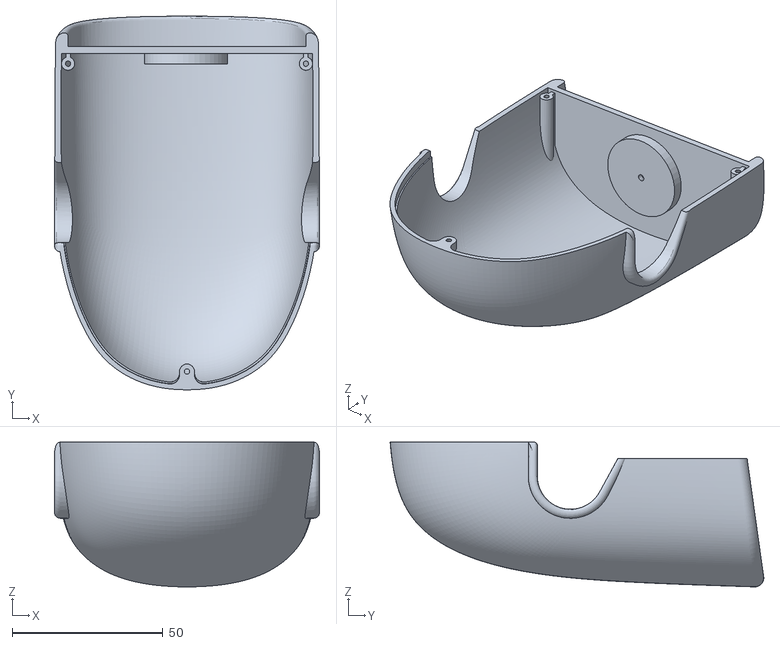
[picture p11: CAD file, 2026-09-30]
structure/head_shell.stl
88.0 x 124.1 x 48.1

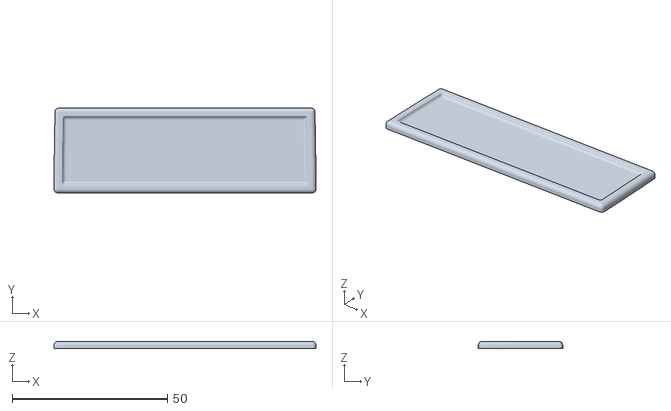
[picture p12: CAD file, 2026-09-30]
structure/mouth_up_tpu.stl
84.3 x 27.2 x 2.40

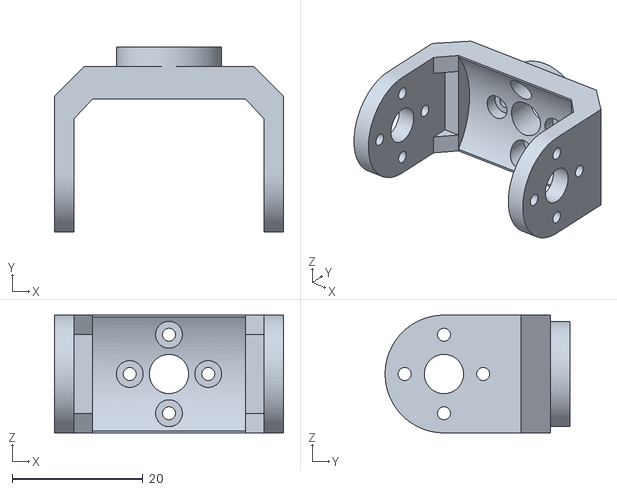
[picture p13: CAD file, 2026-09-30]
structure/head_pitch.stl
35.0 x 28.2 x 18.0

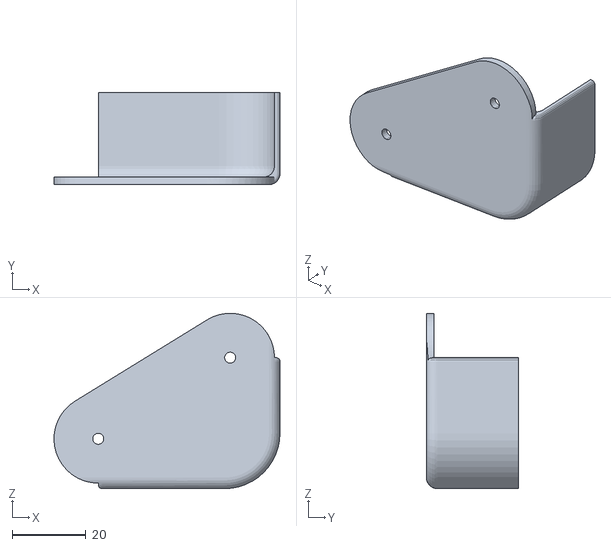
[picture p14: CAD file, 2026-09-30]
structure/thigh_right_shell.stl
61.2 x 25.0 x 47.5

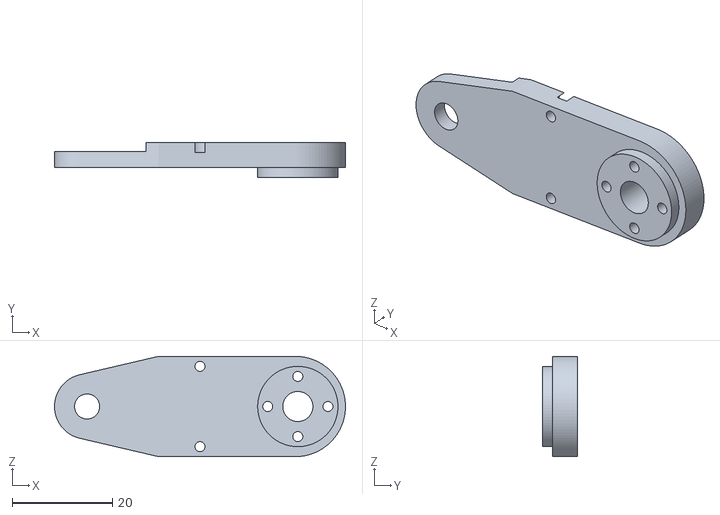
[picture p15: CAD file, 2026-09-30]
structure/2x_shank.stl
58.0 x 7.00 x 20.0

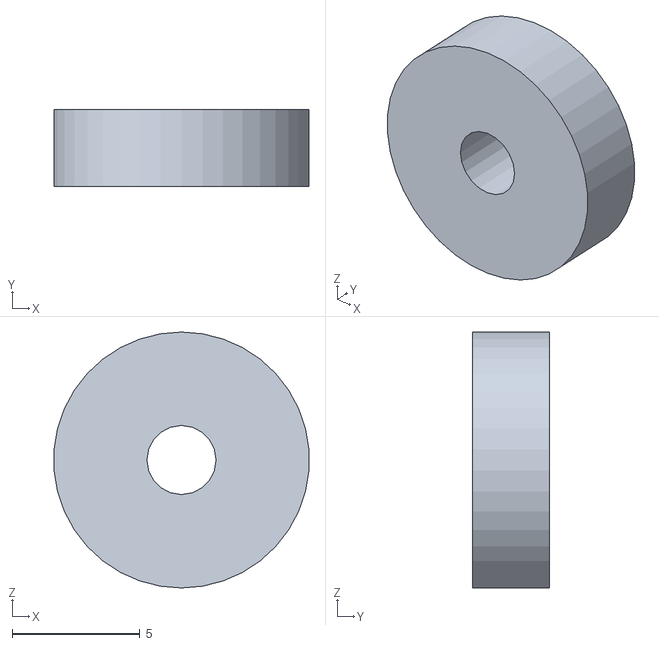
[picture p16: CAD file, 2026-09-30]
structure/2x_ankle_axis.STL
9.97 x 3.00 x 10.0

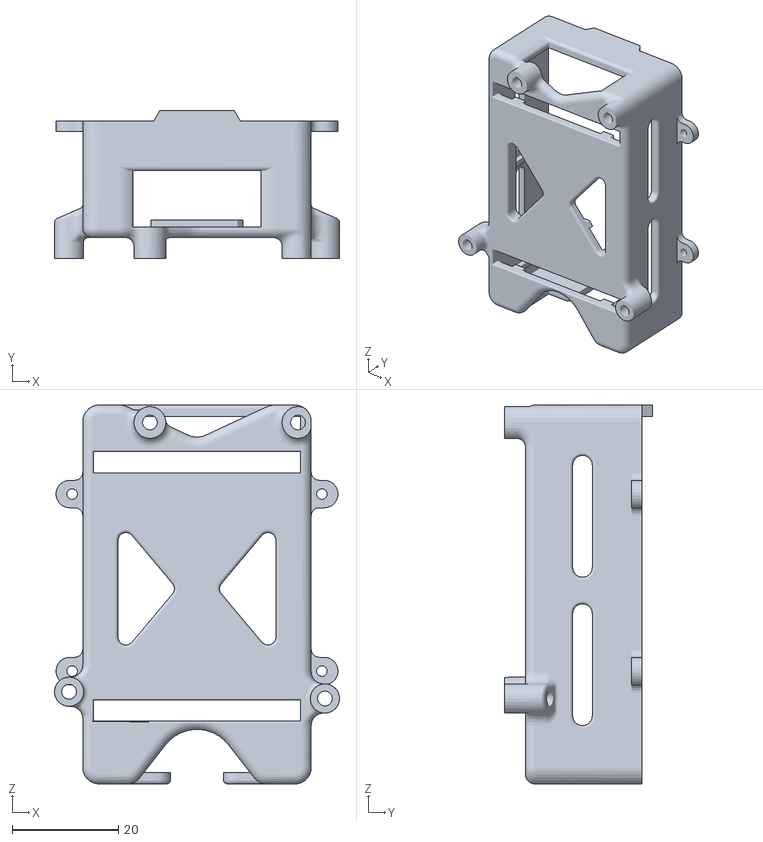
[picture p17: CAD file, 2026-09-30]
structure/battery.stl
53.8 x 28.0 x 71.5

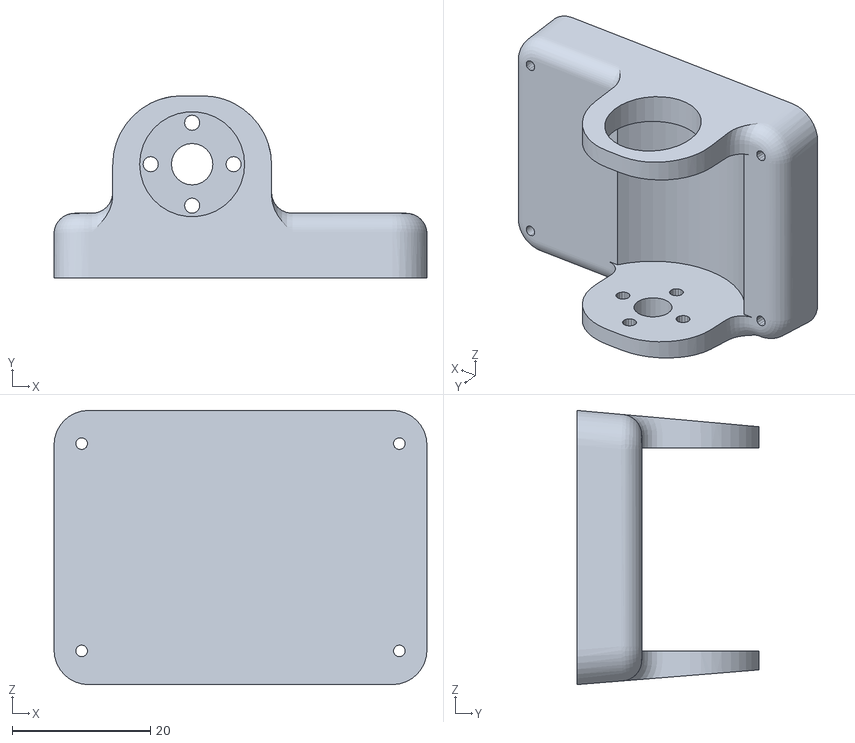
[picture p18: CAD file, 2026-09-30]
structure/left_foot.stl
54.0 x 26.4 x 39.7

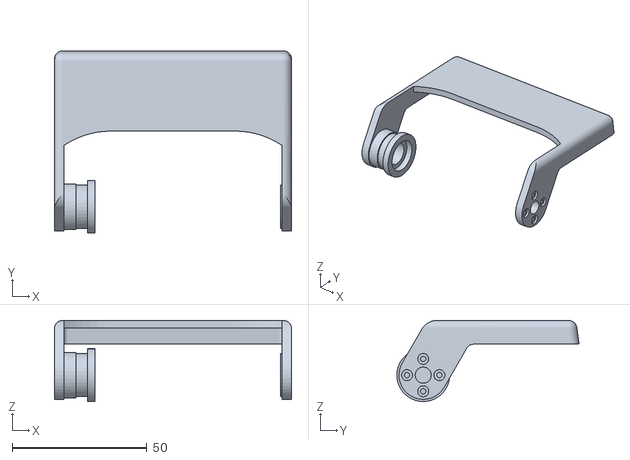
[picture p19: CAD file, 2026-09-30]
structure/jaw.stl
88.0 x 67.7 x 30.1

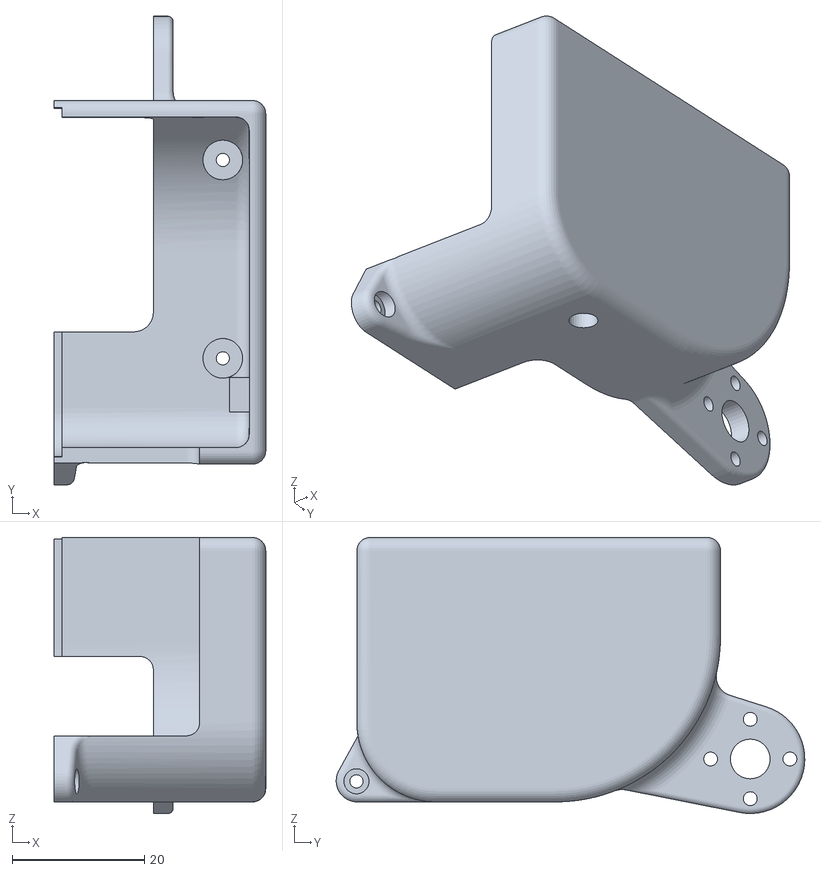
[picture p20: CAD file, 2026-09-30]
structure/body_left_shell.stl
32.0 x 70.9 x 41.7

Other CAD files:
structure/thigh_left_shell.stl
structure/2x_hip_yaw2rol.STL
structure/body_right_shell.stl
structure/hip_yaw_support.STL
PCBA/ArduinoUnoQ.DWG
structure/2x_hip_rol_output.stl
structure/2x_hip_rol_shell.stl
structure/2x_neck.stl
structure/2x_thigh_support.stl
structure/body.stl
structure/eye.stl
structure/eye_shell.stl
structure/head.stl
structure/head_servo_support.stl
structure/right_foot.stl

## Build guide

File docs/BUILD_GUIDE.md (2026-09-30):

# Build and first-power workflow

[Project](../readme.md) · [BOM](BOM.md) · [Print inventory](PRINTING.md) · [Troubleshooting](TROUBLESHOOTING.md)

Use this guide alongside the [25-page assembly PDF](../Assembly_Guide.pdf). The PDF's photographs determine orientations and cable routing. The sequence below adds preparation and inspection checkpoints; it does not invent missing torque values, connector polarity or mechanical-zero drawings.

## 1. Establish a matched build

Record the hardware, runtime and RL revisions you use. Inventory the BOM, identify every printed part and check the actuator model. Obtain the battery/power details in [BOM.md](BOM.md) before powering the board. Keep a multimeter, the appropriate screwdrivers, cable labels and a stable robot support available. Choose print settings only after validating fit on a representative bearing/servo interface.

## 2. Prepare the board and individual servos

Inspect the assembled expansion board against `PCBA/ArduinoUnoQ.pdf`, including component orientation and shorts. PCB fabrication settings and a tested board bring-up procedure are not yet supplied; have the board reviewed before connecting the controller or servos.

Deploy the [runtime](https://github.com/LuwuDynamics/xgoduck_runtime_arduino) on Uno Q before configuring servos. Connect **one servo at a time**. In Servo setup, assign unique IDs 10–14, 20–24 and 30–34, center at raw 2047, then write stored gains according to the runtime guide. Label each servo. Duplicate IDs can receive the same write.

## 3. Follow the assembly drawings

| PDF pages | Focus and checks |
| --- | --- |
| 1 | Servo ID placement. Match physical labels to the photos before installing. |
| 2 | Secondary shafts: retain on IDs 30 and 31. Removal on 10, 20 and 32 is optional per the guide. Do not remove the output shafts. |
| 3–5 | Initial structure and cable routing. Page 3 explicitly delays screw installation. Follow the pictured sequence. |
| 6–10 | Leg assembly. Connect cables before the indicated joints become enclosed; left/right orientations differ on page 8. |
| 11–15 | Feet and sole assembly. Page 11 calls out the 10 × 15 × 3 bearing and M2.5 × 6 screw; page 14 also calls out M2.5 × 6. Check the TPU sole direction on page 15. |
| 16–20 | Head/neck mechanism around IDs 32–34. Connect the bottom cables before closing the assembly on page 17. |
| 21 | Adhesive operation shown in the drawing. Adhesive type/cure time are not specified; confirm material compatibility. |
| 22–23 | IDs 30/31 and the M3 × 16 screw locations. |
| 24–25 | Follow final pictured assembly and inspect the completed routing. |

Before closing each section, check that the harness cannot be pinched and has slack through the intended movement. Compare mirrored parts to the photos; do not assume left and right mountings are identical. Do not force printed bearing seats or infer tightening torque from screw size.

## 4. Inspect before enabling motion

- All 15 unique IDs answer; the mouth is ID 34.
- Mechanical assembly matches the PDF and cables clear the joints.
- Polarity and supply limits have been confirmed from the matched hardware revision.
- The robot is supported with joints clear of hands and obstructions.
- The runtime reports fresh MCU feedback and a working IMU.

## 5. Calibrate, then test in stages

Use the runtime calibration procedure. Starting calibration commands the servos to raw 2047 and can move them. Factory zero values are a reference from another assembly, not a substitute for calibrating your robot. A per-joint mechanical-zero photo set is still needed for unambiguous first-time reproduction; obtain it before completing zero calibration.

Back up `data/zero_pos.json` privately. Start with inference only, then a supported default-pose test, then low-command walking on a clear level surface. Check torque-off behavior before testing pick or recovery. A torque-off robot can collapse; use a support. Stop on unexpected direction, binding, heat or unstable feedback and diagnose before retrying.

## Record your build

Record printer/material/profile, board revision, servo supplier/firmware, power pack, three repository commits, policy hashes, calibration date and motion-test observations. These details make a useful issue report and let another maker repeat your result.

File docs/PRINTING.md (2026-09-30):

# Printing inventory

[Project](../readme.md) · [Build guide](BUILD_GUIDE.md)

Quantities below follow the repository naming rule: `2x_` means two copies; other files default to one for planning and require confirmation against the assembly. Left/right files are distinct. Original filenames, including `mouth_buttom_tpu.stl`, are preserved so links remain compatible.

| File | Planned copies | Material note |
| --- | ---: | --- |
| [2x_ankle_axis.STL](../structure/2x_ankle_axis.STL) | 2 | Rigid material: confirm profile |
| [2x_foot_bottom_tpu.stl](../structure/2x_foot_bottom_tpu.stl) | 2 | TPU indicated by filename |
| [2x_hip_rol_output.stl](../structure/2x_hip_rol_output.stl) | 2 | Rigid material: confirm profile |
| [2x_hip_rol_shell.stl](../structure/2x_hip_rol_shell.stl) | 2 | Rigid material: confirm profile |
| [2x_neck.stl](../structure/2x_neck.stl) | 2 | Rigid material: confirm profile |
| [2x_shank.stl](../structure/2x_shank.stl) | 2 | Rigid material: confirm profile |
| [2x_thigh_support.stl](../structure/2x_thigh_support.stl) | 2 | Rigid material: confirm profile |
| [battery.stl](../structure/battery.stl) | 1 | Rigid material: confirm profile |
| [body.stl](../structure/body.stl) | 1 | Rigid material: confirm profile |
| [body_left_shell.stl](../structure/body_left_shell.stl) | 1 | Rigid material: confirm profile |
| [body_right_shell.stl](../structure/body_right_shell.stl) | 1 | Rigid material: confirm profile |
| [eye.stl](../structure/eye.stl) | 1 | Rigid material: confirm profile |
| [eye_shell.stl](../structure/eye_shell.stl) | 1 | Rigid material: confirm profile |
| [head.stl](../structure/head.stl) | 1 | Rigid material: confirm profile |
| [head_pitch.stl](../structure/head_pitch.stl) | 1 | Rigid material: confirm profile |
| [head_servo_support.stl](../structure/head_servo_support.stl) | 1 | Rigid material: confirm profile |
| [head_shell.stl](../structure/head_shell.stl) | 1 | Rigid material: confirm profile |
| [head_yaw.STL](../structure/head_yaw.STL) | 1 | Rigid material: confirm profile |
| [hip_yaw2rol.STL](../structure/hip_yaw2rol.STL) | 1 | Rigid material: confirm profile |
| [hip_yaw_support.STL](../structure/hip_yaw_support.STL) | 1 | Rigid material: confirm profile |
| [jaw.stl](../structure/jaw.stl) | 1 | Rigid material: confirm profile |
| [left_foot.stl](../structure/left_foot.stl) | 1 | Rigid material: confirm profile |
| [mouth_buttom_tpu.stl](../structure/mouth_buttom_tpu.stl) | 1 | TPU indicated by filename |
| [mouth_up_tpu.stl](../structure/mouth_up_tpu.stl) | 1 | TPU indicated by filename |
| [right_foot.stl](../structure/right_foot.stl) | 1 | Rigid material: confirm profile |
| [thigh_left_shell.stl](../structure/thigh_left_shell.stl) | 1 | Rigid material: confirm profile |
| [thigh_right_shell.stl](../structure/thigh_right_shell.stl) | 1 | Rigid material: confirm profile |

## Print profile still required

The release needs tested values for material brand/type, nozzle, layer height, walls, infill, supports, orientation, scale and tolerances, with finished-part photographs. TPU hardness is also unspecified. No recommended print time or filament mass has been measured here.

Before a full print, check one servo mount and one bearing seat, inspect left/right orientation and verify cable clearance. Record your settings and report fit results with the part filename. A slicer project from a different revision is not a verified profile for these STLs.

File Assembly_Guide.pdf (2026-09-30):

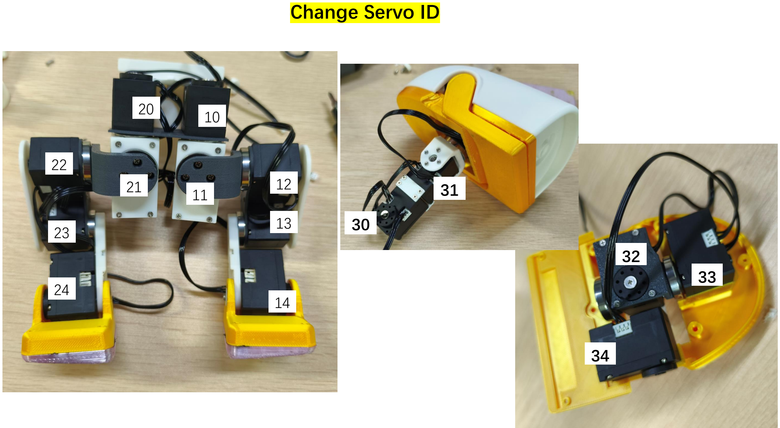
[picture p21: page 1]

Change Servo ID

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
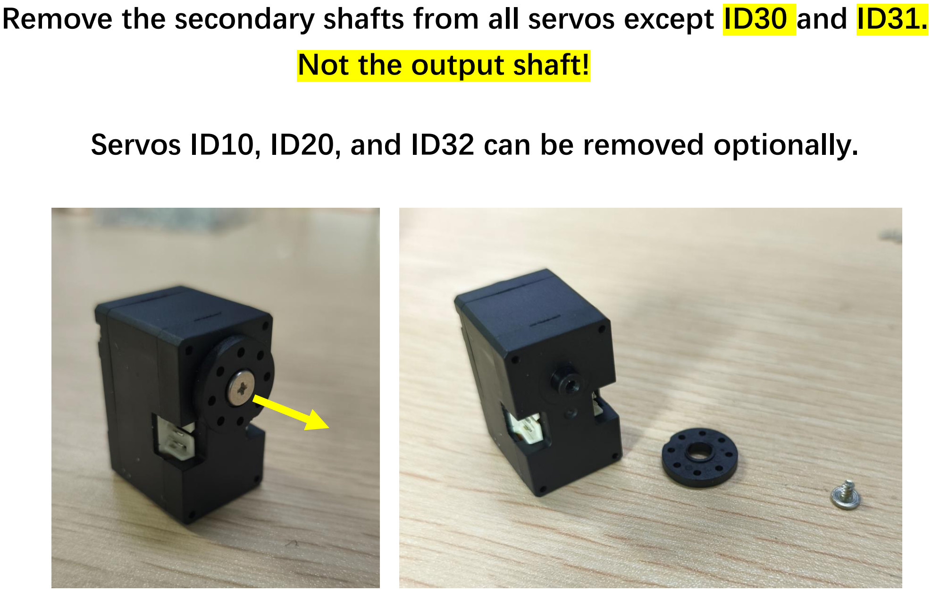
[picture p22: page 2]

Remove the secondary shafts from all servos except ID30 and ID31. Not the output shaft!

Servos ID10, ID20, and ID32 can be removed optionally.

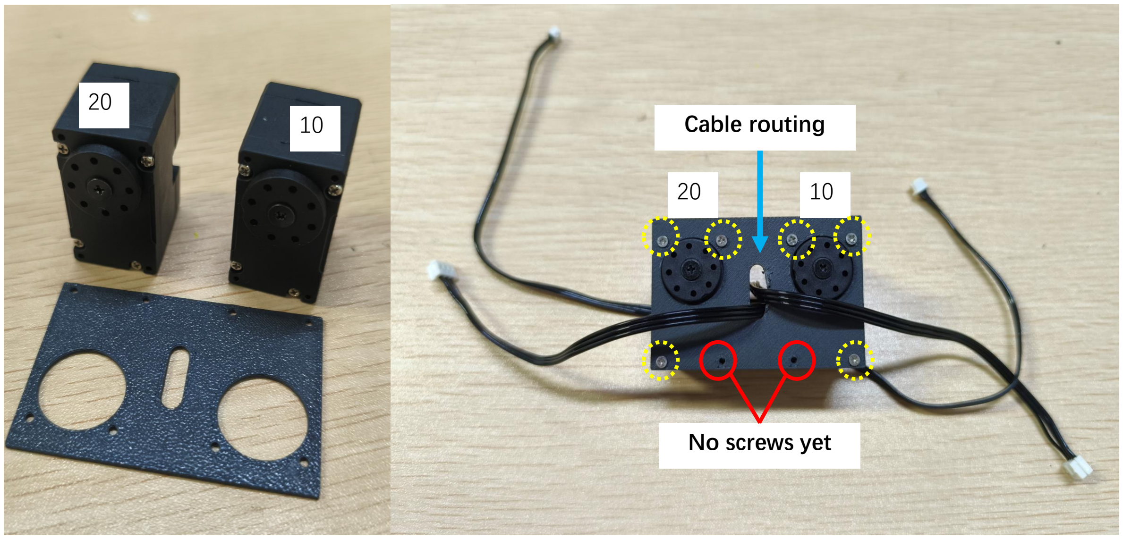
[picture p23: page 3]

10

20

20 | 10

Cable routing

No screws yet

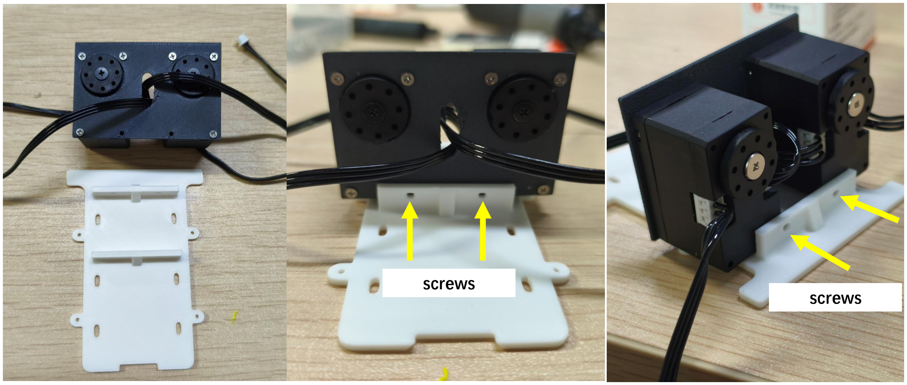
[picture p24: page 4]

screws
screws

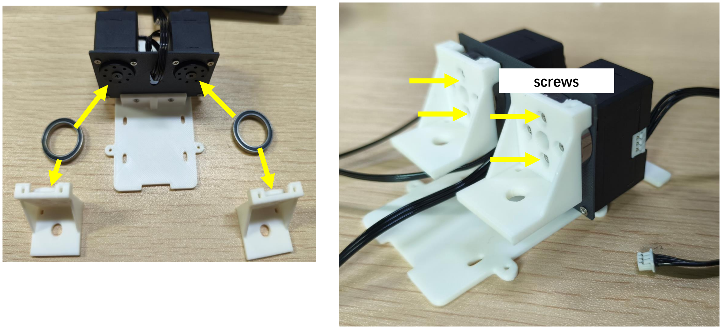
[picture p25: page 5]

screws

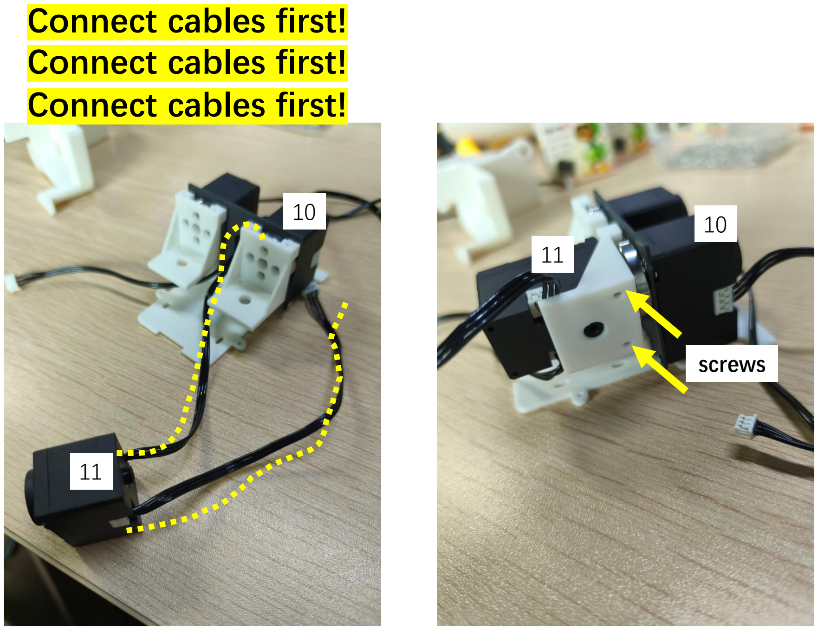
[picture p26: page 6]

10

11

11

10

screws

Connect cables first!
Connect cables first!
Connect cables first!

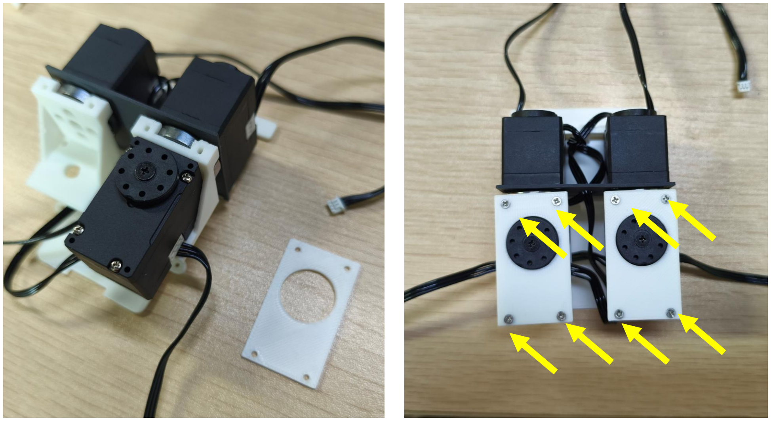
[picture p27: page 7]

## Left and right orientations differ!

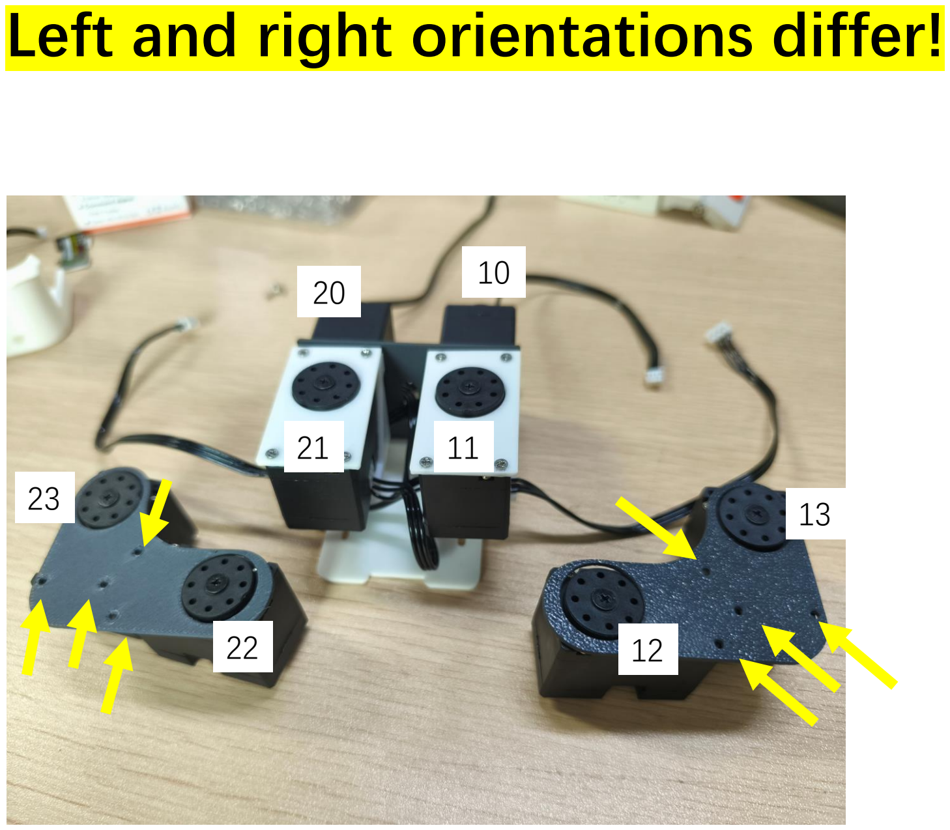
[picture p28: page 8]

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
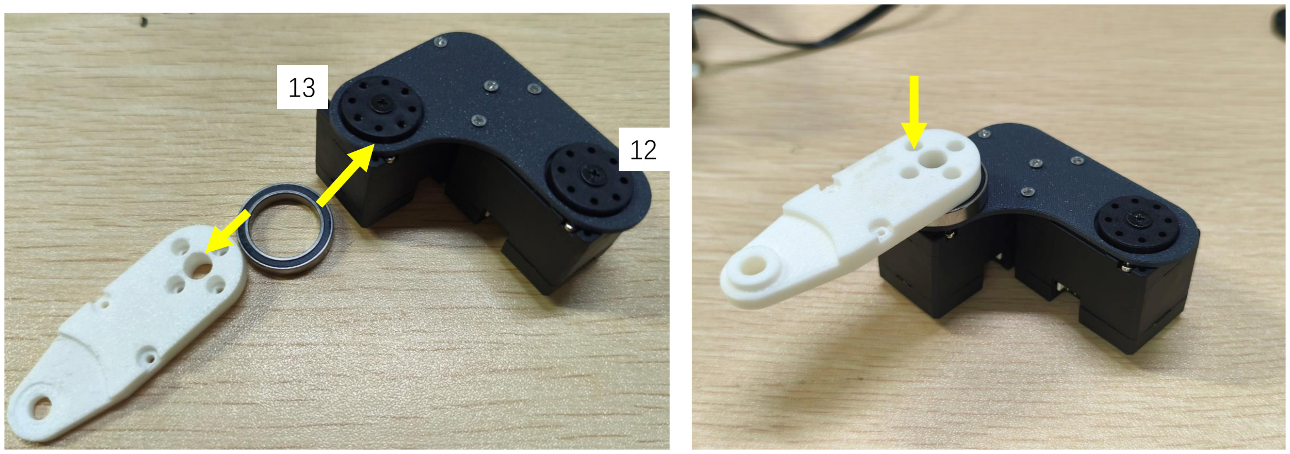
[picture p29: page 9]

12

13

Connect cables first!

### 13 to 14

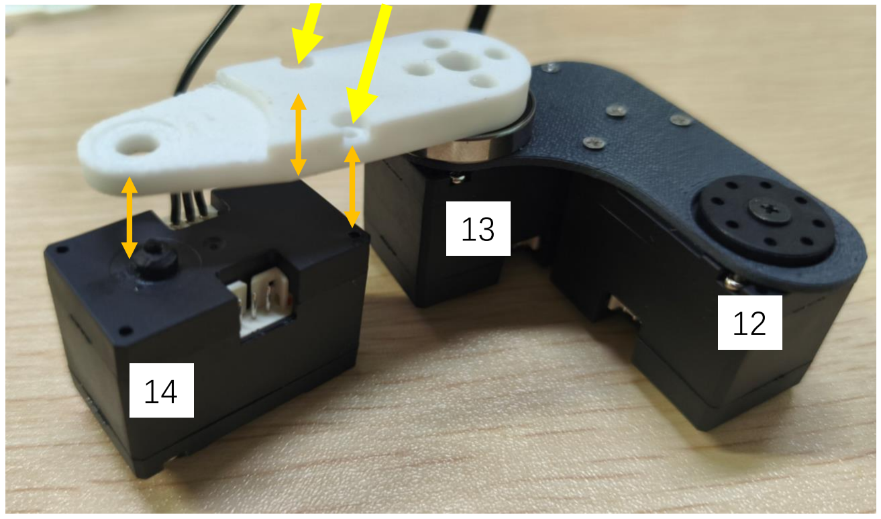
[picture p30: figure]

screws

Distinguish the left and right feet.

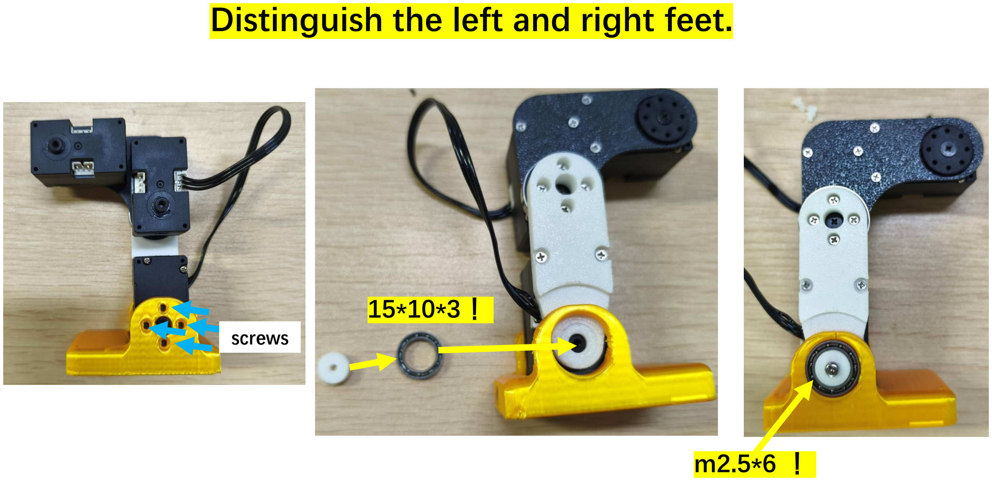
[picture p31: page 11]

screws

15*10*3 ！

m2.5*6 ！

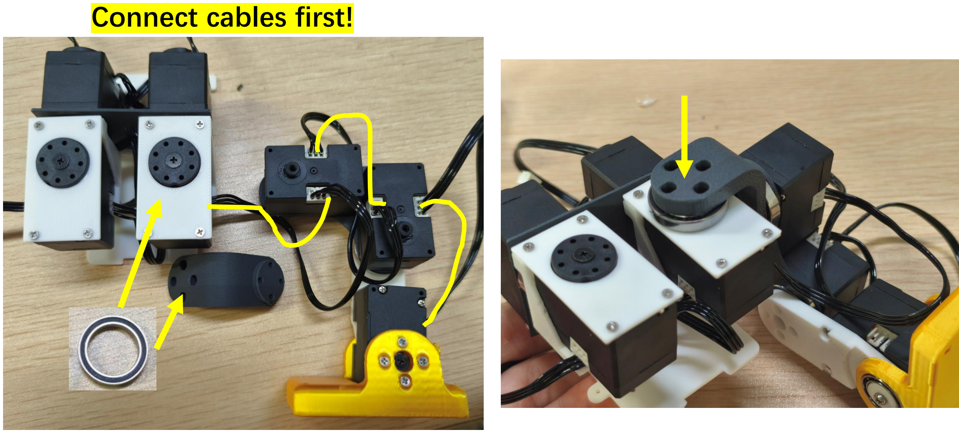
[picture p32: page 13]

Connect cables first!

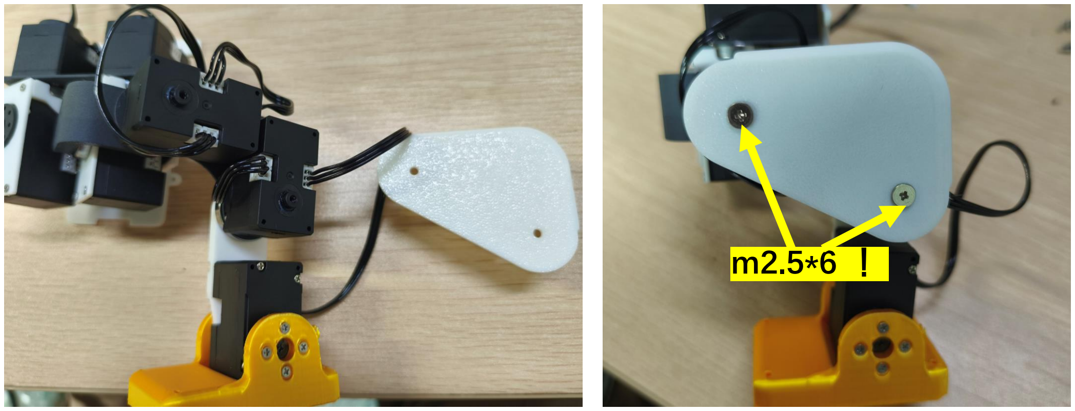
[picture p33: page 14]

m2.5*6 ！

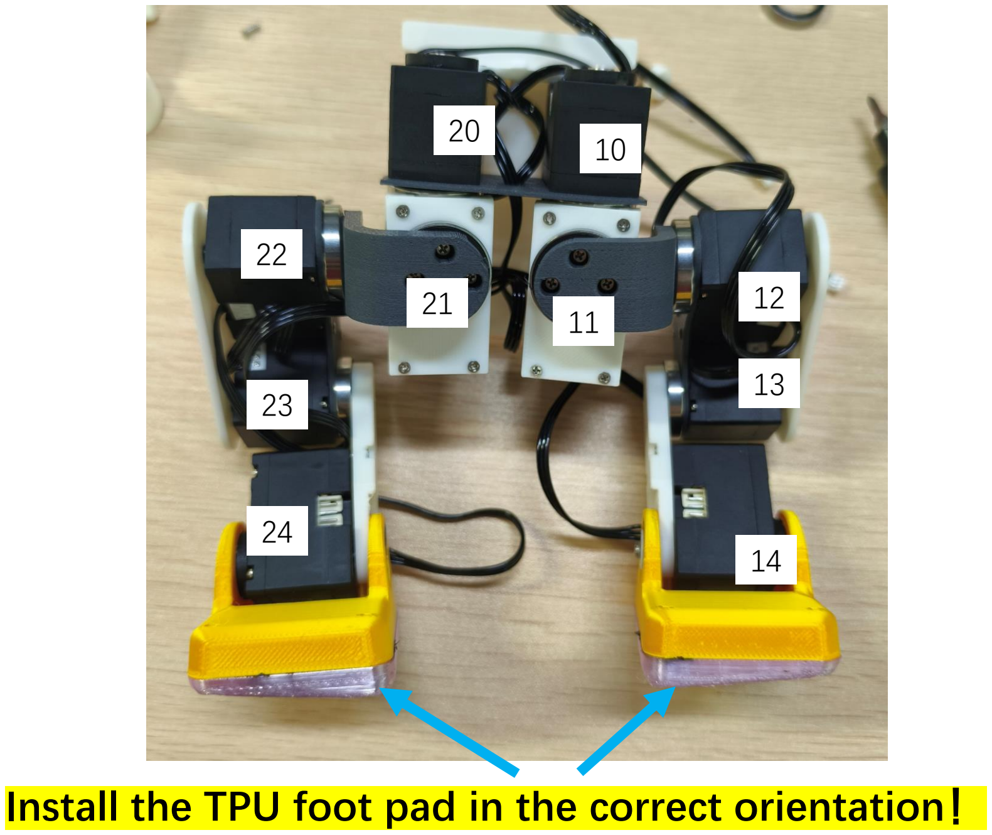
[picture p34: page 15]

Install the TPU foot pad in the correct orientation！

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
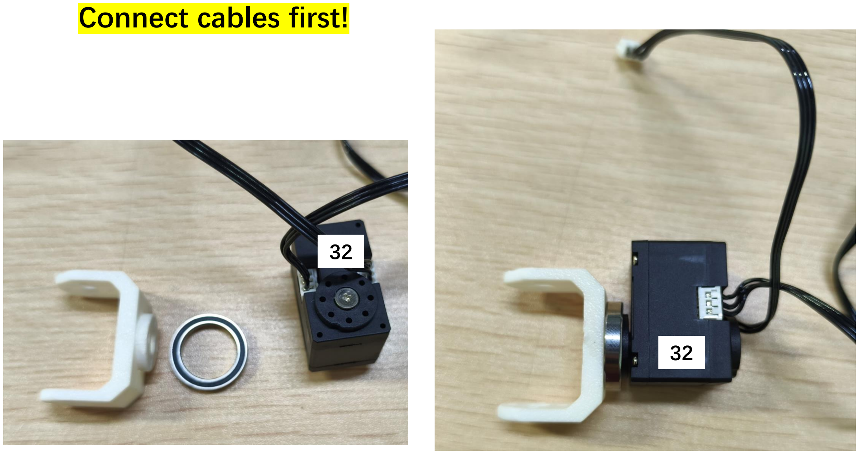
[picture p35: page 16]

32

32

Connect cables first!

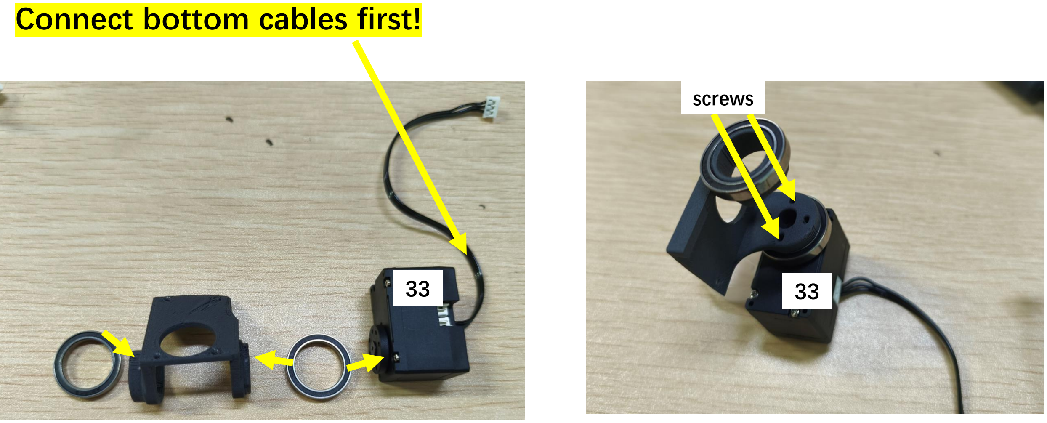
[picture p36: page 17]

Connect bottom cables first!

33 33

screws

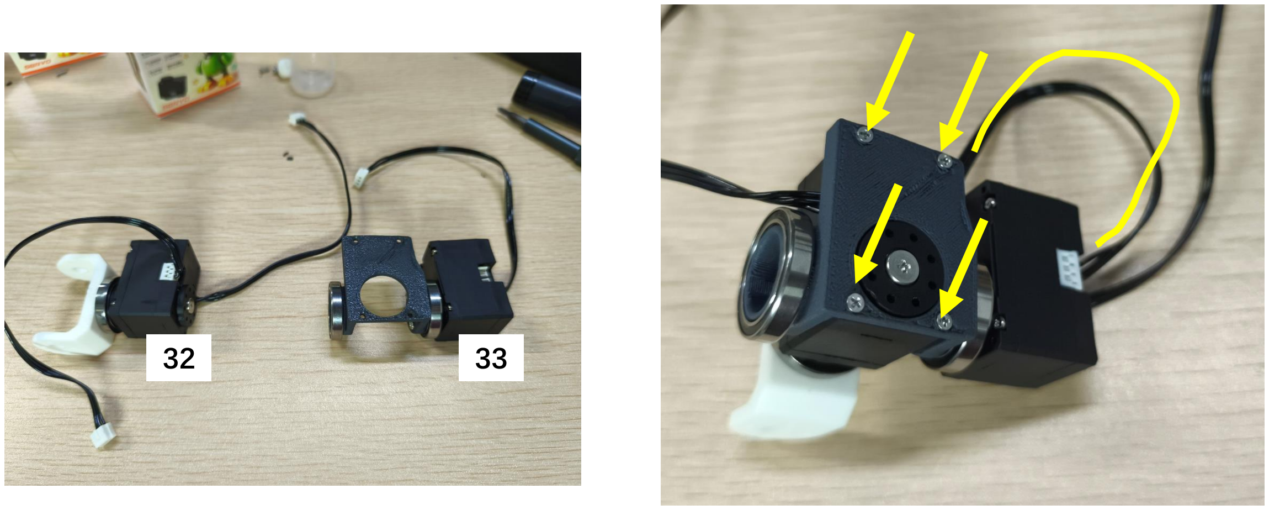
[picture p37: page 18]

32 33

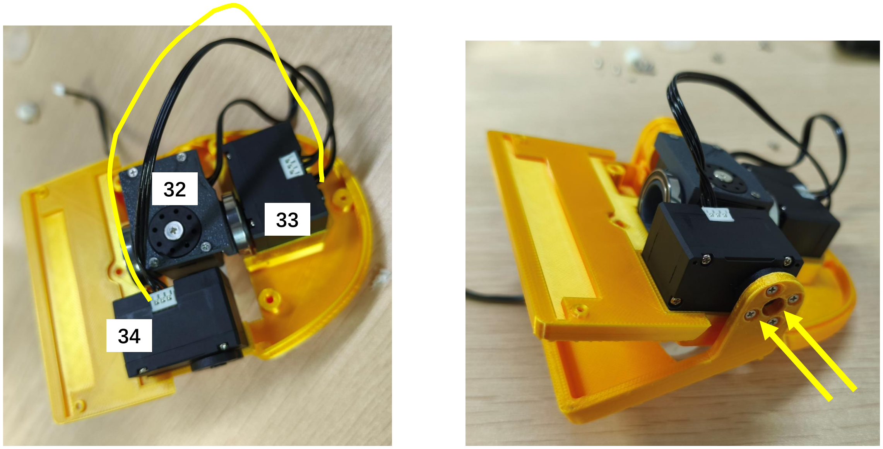
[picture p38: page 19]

33

32

34

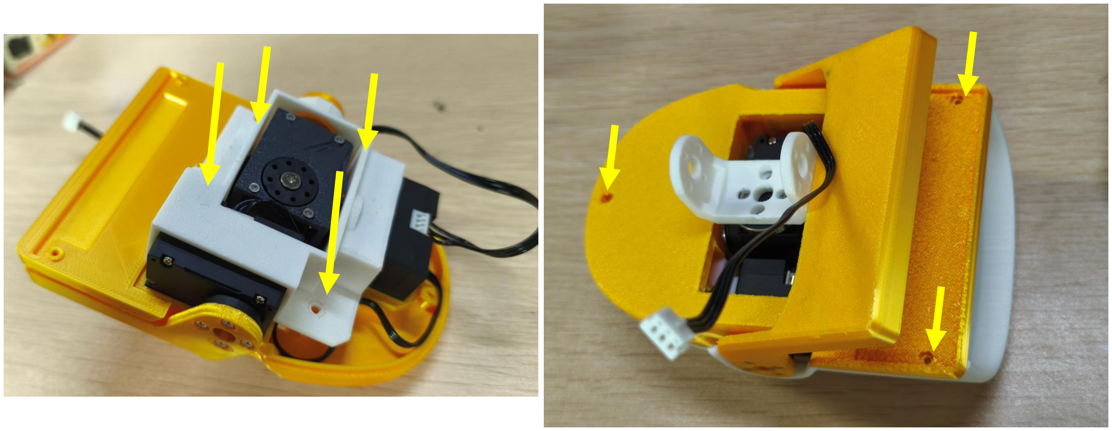
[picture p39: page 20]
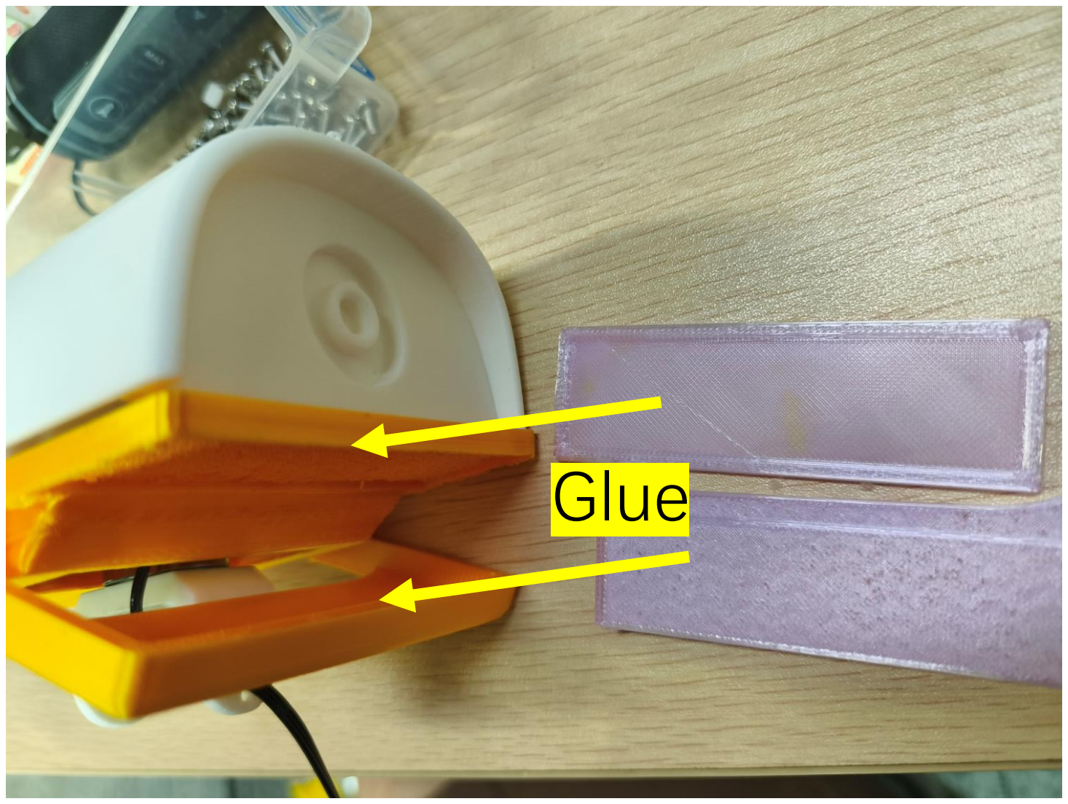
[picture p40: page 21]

## Glue

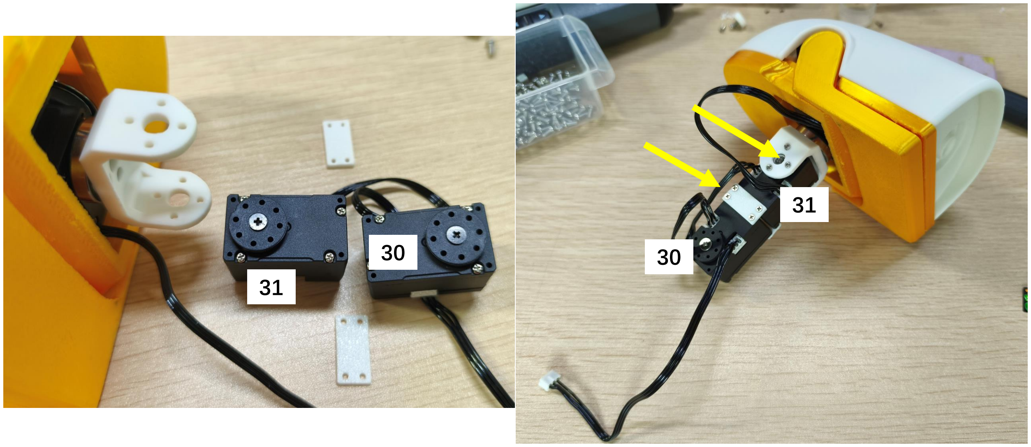
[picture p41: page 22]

31

30 30

31

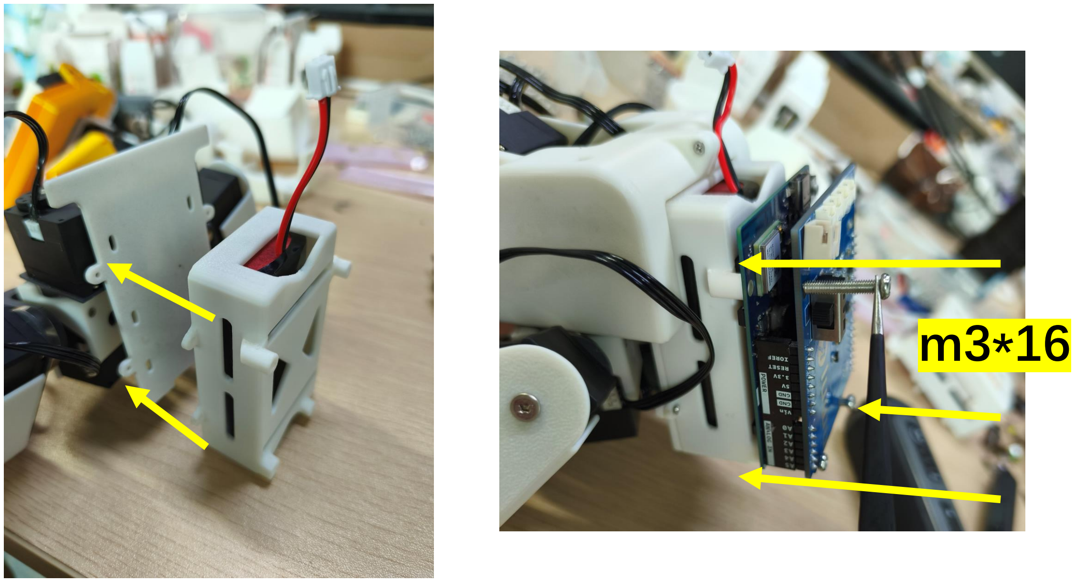
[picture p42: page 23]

m3*16

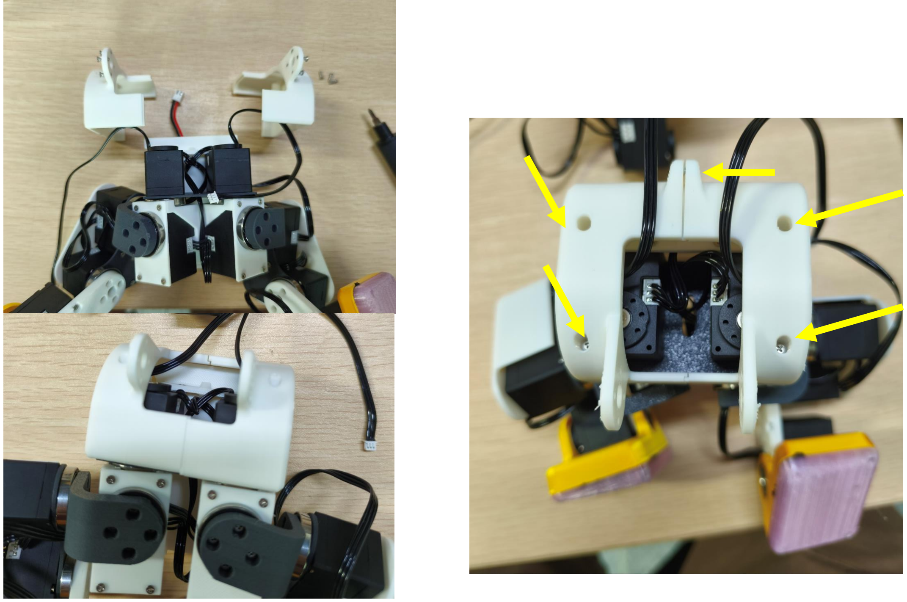
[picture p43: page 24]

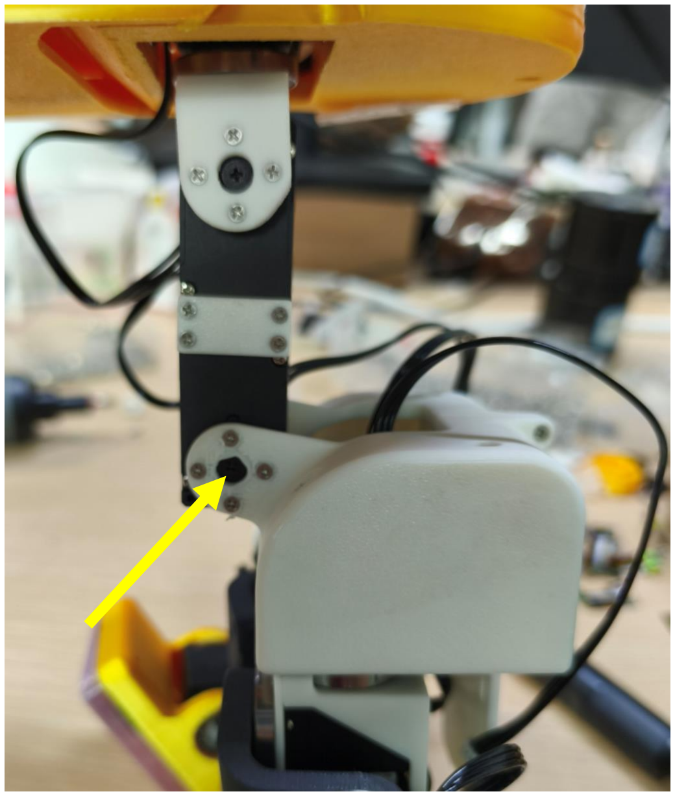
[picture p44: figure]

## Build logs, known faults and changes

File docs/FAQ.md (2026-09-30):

# Maker FAQ

[Project](../readme.md) · [Build guide](BUILD_GUIDE.md) · [Origins](../UPSTREAM.md)

## What is XGO-Duck?

A Microduck-based biped project adapted by Luwu Dynamics for Arduino Uno Q, a custom expansion board and Feetech 1910 servos. It publishes hardware resources, a training environment and an onboard runtime in separate repositories.

## Do I need to train a model before building?

No. The Arduino runtime contains walk, get-up and pick ONNX files. You still need the matching hardware, servo setup and calibration. Start with the bundled set before experimenting with new policies.

## Can I explore without a robot?

Yes. Inspect the build and control code, or use the XGO-Duck training repository on a suitable CUDA machine. No XGO-Duck browser simulator has been validated or published in this package. The [Microduck simulator](https://huggingface.co/spaces/pollen-robotics/microduck-simulator) is an upstream learning reference, not a simulation of the Uno Q variant.

## Is this a ready-to-use product or a kit?

These repositories describe a maker build. A purchasable kit, inventory, retail price and delivery schedule have not been supplied. Contact hello@xgorobot.com for availability questions. The approximately US$400 figure is a build estimate, not a purchase offer.

## How long does assembly take?

There is no validated assembly-time estimate yet. Printing, sourcing, PCB preparation and calibration depend on your equipment and experience. A first independent build should record both working time and blockers.

## Can I use Microduck software or policies unchanged?

Do not assume so. Use the [XGO-Duck runtime contract](https://github.com/LuwuDynamics/xgoduck_runtime_arduino) and the [policy handoff guide](https://github.com/LuwuDynamics/xgoduck_rl). Matching dimensions do not prove matching dynamics or command semantics.

## What does it do today?

The runtime contains walking, get-up and pick control paths. Other training tasks are experiments until they have a matching runtime integration and repeatable hardware evidence. Camera-based behavior, voice, skating and additional upstream behaviors are not established XGO-Duck capabilities in this release.

## Can I change the shell or actuator?

Treat mechanical changes as control changes when they alter mass, inertia, joint limits or foot contact. Recheck fit and calibration; compare the simulation model and evaluate whether retraining is required. A visually similar servo is not necessarily a compatible actuator.

## How can I contribute before owning one?

Check instructions, improve diagrams, identify missing information, review source provenance or reproduce a simulation result. See [Community](../COMMUNITY.md) for concrete contributions and how to report evidence.

## Can I sell a build or use it commercially?

Read [Licensing](../LICENSING.md) for the specific material. Existing Apache-2.0 code rights remain in place; design and model terms require separate review. Contact the team for material needing additional authorization.

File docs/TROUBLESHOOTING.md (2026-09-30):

# Hardware troubleshooting

[Build guide](BUILD_GUIDE.md)

Disable motion and support the robot before inspecting mechanics. Disconnect power before changing connectors.

| Symptom | Inspect first | Next action |
| --- | --- | --- |
| Two servos respond together | Duplicate IDs | Disconnect the shared bus and configure one servo at a time |
| One servo is missing | ID label, connector seating, harness continuity | Test it separately with confirmed compatible power and protocol |
| Joint moves the wrong way | ID location, left/right installation, zero calibration | Compare PDF and runtime mapping; do not compensate by changing policy order |
| Bearing or servo does not fit | Exact part number, print scale, orientation and tolerances | Validate one part before reprinting the whole set |
| Robot resets during movement | Supply voltage under load, connector and cable capacity | Stop and verify the complete power path; do not keep retrying with a hotter supply |
| Default pose binds | Assembly orientation, joint zero, trapped cable | Release torque with the robot supported; correct the mechanical cause |
| Oscillation or heat | Calibration, gains, mechanical resistance | Stop motion; compare with the documented configuration before tuning |
| No IMU data | Board orientation, soldering, I²C connection | Inspect against the schematic and runtime IMU diagnostics |

For help, include the hardware revision, servo part/firmware, power-pack details, clear wiring photos and the runtime status capture. Avoid publishing Wi-Fi credentials, IP-sensitive logs or personal purchase information.

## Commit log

2026-09-30 Add XGO Duck hardware files for Arduino Uno Q
    [2x_ankle_axis.STL, 2x_foot_bottom_tpu.stl, 2x_hip_rol_output.stl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]
2026-09-30 Update XGO-Duck hardware documentation and convert robot BOM to Markdown
    [bom.xlsx]
2026-09-30 docs: restore missing BOM items and purchase links
2026-10-02 Fix U3 U4 U5 connector pinout and document old-board wiring workaround
    [ArduinoUnoQ.PcbDoc, ArduinoUnoQ.SchDoc]
2026-10-02 Trim connector correction notice in Chinese and English
2026-10-09 Add partner PCB supplier contact details
2026-10-10 docs: correct XGO-Duck fastener specs and head shapes
    Update BOM items 7–9 and align the English and Chinese READMEs with the corrected screw types and quantities.
    Add fastener shape artwork, the supplied round-head reference photo, and sourcing notes that distinguish the flat-topped M2.3 screw from the domed M3 machine screw.
2026-10-10 Optimize model structure
    [head_yaw.STL]
2026-10-13 docs: update assembly guide
2026-10-20 Emphasize hardware testing-only scope and servo precautions
2026-10-21 Add print orientation reference and slicing instructions
2026-10-22 Update ArduinoUnoQ schematic and BOM and simplify servo notice
2026-10-23 Add roller skate STL files and update hardware documentation
2026-10-23 docs: replace servo kit link with electronics kit option
2026-10-26 Publish ArduinoUnoQ V1.1 and preserve previous PCBA files in archive
2026-10-26 Add V1.1 DWG and STEP files and remove PCBA warning
2026-10-26 Add board photo and reverse-connection and servo stall test videos
2026-10-26 Present PCBA media in README and move assets out of design directory
2026-10-26 Highlight project files as authoritative over board photos and videos
2026-10-26 Embed GitHub-hosted test video players in PCBA README
2026-10-27 Update BOM.md
    Recommend 3500 mAh, 3C or 5C discharge rating for reliable robot system operation.
2026-10-30 Optimized the battery compartment design
2026-11-04 Add charging power-switch warning to README
2026-11-04 Make charging warning a separate prominent notice at top of README
2026-11-05 Add charging troubleshooting for green indicator and zero-volt battery output
2026-11-05 Document recovery for confirmed protection-board cutoff with healthy cells
2026-11-05 Simplify battery recovery applicability paragraph as requested
2026-11-05 Change battery recovery supply duration to 10-20 seconds
2026-11-06 Update ArduinoUnoQ schematic and manufacturing files from supplied revision
2026-11-07 Move charging guidance to PCBA and provide English and Chinese READMEs
2026-11-08 Update STL parts for the final original XGO-Duck design
2026-11-08 Update STL parts for the final audio/video XGO-Duck design
2026-11-11 Add V2 and V5 3MF print projects with bilingual download and plate guides
2026-11-13 Add separate V2 standard and V5 audio/video STL sets
    Add 47 individual V2 parts under structure/v2 with V2_STANDARD_ names
    and 50 V5 parts under structure/v5 with V5_AUDIO_VIDEO_ names. Preserve
    the supplied STL bytes and existing files directly under structure.
    Add bilingual guides for both versions and update the project entry
    points and printing inventory, including numbered-instance quantities.
    Validation: all 97 staged STL hashes match the supplied archive; all
    198 relative references across nine affected documents resolve; git
    diff --check passes. Geometry was previously checked against both 3MF
    sources. No slicing or physical print testing was performed.
2026-11-13 Keep only named V2 standard and V5 audio/video structure folders
    Remove the 35 old STL files directly under structure and rename the
    version folders to V2_STANDARD_ and V5_AUDIO_VIDEO_. Keep all 97 versioned
    STLs and four bilingual guides unchanged within their renamed folders.
    Update the project and 3MF guides and replace the old printing inventory
    links with the versioned files.
    Validation: all 101 moved files match their prior contents, all 97 STL
    hashes match the source archive, and all 255 relative links across the
    repository's 22 Markdown documents resolve. git diff --check passes.
